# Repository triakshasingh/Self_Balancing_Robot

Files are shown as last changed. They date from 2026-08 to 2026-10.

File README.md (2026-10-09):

# Self-Balancing Robot

A two-wheeled inverted-pendulum robot built around a NodeMCU ESP-32S. The
board carries the MCU, an IMU, a dual H-bridge motor driver and the power rail;
firmware fuses accelerometer and gyroscope readings into a tilt angle and runs a
PID loop that drives the wheels to keep the chassis upright.

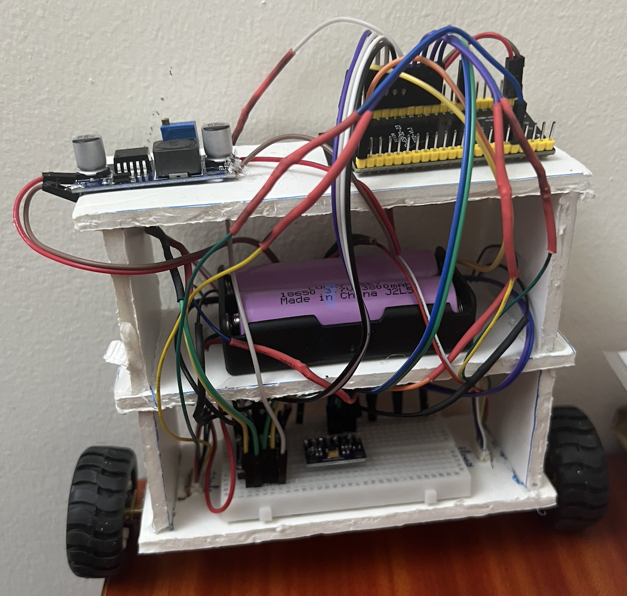
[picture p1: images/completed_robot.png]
Completed robot

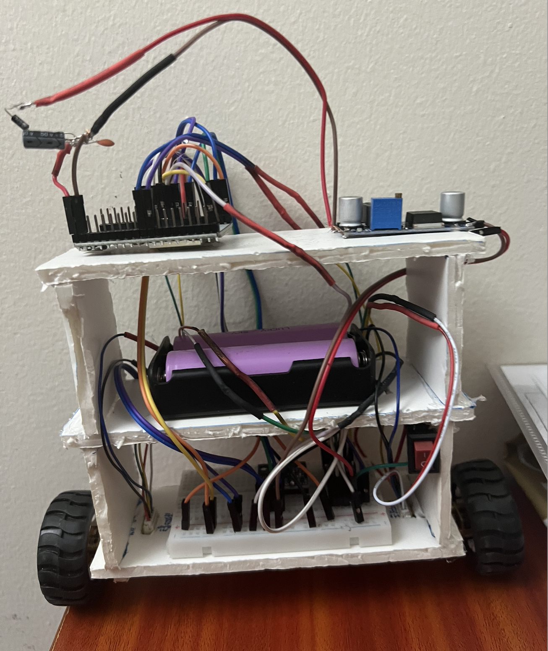
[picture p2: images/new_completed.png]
Rebuilt after board replacement


**During Build**

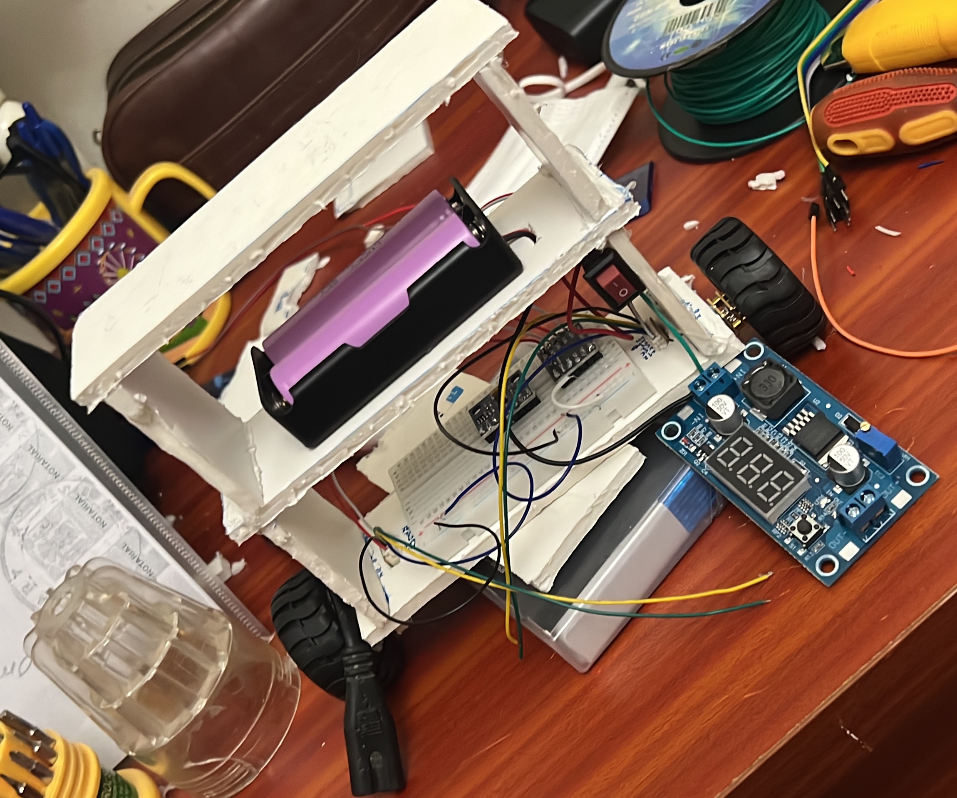
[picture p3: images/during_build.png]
During the build

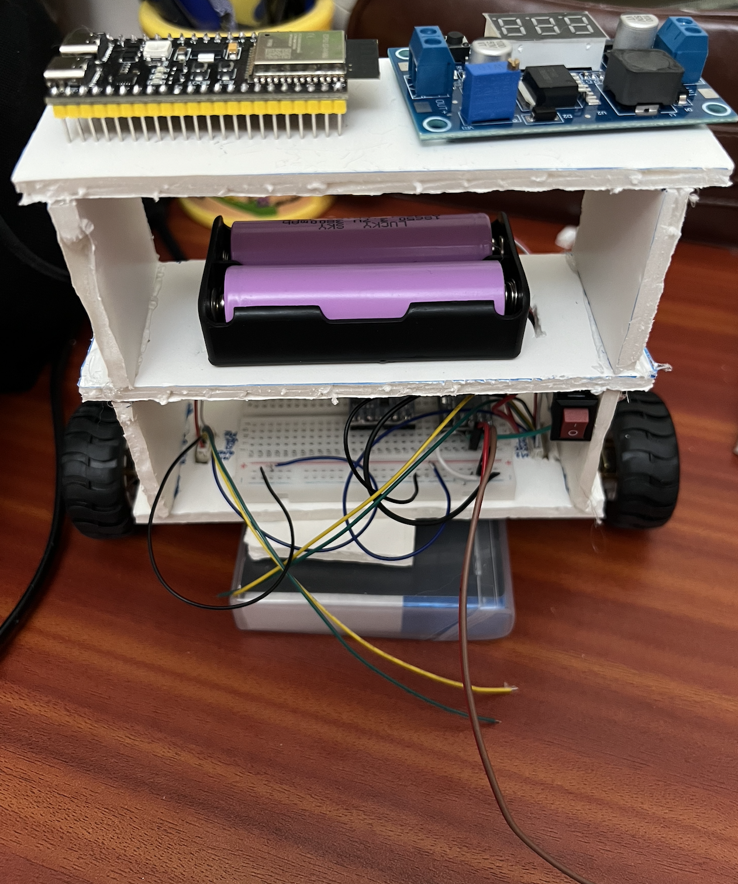
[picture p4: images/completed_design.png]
Design


## Contents

| Path | What's in it |
| --- | --- |
| [PCB/](PCB/) | KiCad 10 project — schematic, board file, project settings |
| [self_balancing_robot_code/self_balancing_robot_code/](self_balancing_robot_code/self_balancing_robot_code/) | Main balancing firmware (Arduino sketch) |
| [self_balancing_robot_code/mpu6050_calibration_only/](self_balancing_robot_code/mpu6050_calibration_only/) | Standalone sketch for finding the upright angle offset |
| [images/](images/) | Build photos and a schematic render |

## Hardware

| Part | Role |
| --- | --- |
| NodeMCU ESP-32S | Main controller, USB programming |
| MPU-6500 (MPU-6050 footprint) | 6-axis IMU over I²C at `0x68` |
| DRV8833PW | Dual H-bridge, drives both gearmotors |
| 2× geared DC motors with quadrature encoders | Drive and wheel odometry |
| Passives | 4.7 kΩ I²C pull-ups, 10 kΩ pull-ups, 0.1 µF / 1 µF / 0.01 µF decoupling |
| Power protection | Backfeed-blocking diode + parallel decoupling capacitors on the 5V rail (added after a brownout incident — see Debugging Notes) |
| 3× push buttons | Boot, reset, user |

The MPU-6500 is pin- and register-compatible with the MPU-6050 footprint used in
the schematic, so the same land pattern works for either part.

### Pin map

GPIO numbers used in the firmware, for the NodeMCU ESP-32S:

| Signal | GPIO |
| --- | --- |
| I²C SDA | 21 |
| I²C SCL | 22 |
| DRV8833 `AIN1` / `AIN2` | 4 / 16 |
| DRV8833 `BIN1` / `BIN2` | 17 / 5 |
| DRV8833 `STBY` | 18 |
| Left encoder `C1` / `C2` | 19 / 23 |
| Right encoder `C1` / `C2` | 25 / 26 |

## PCB

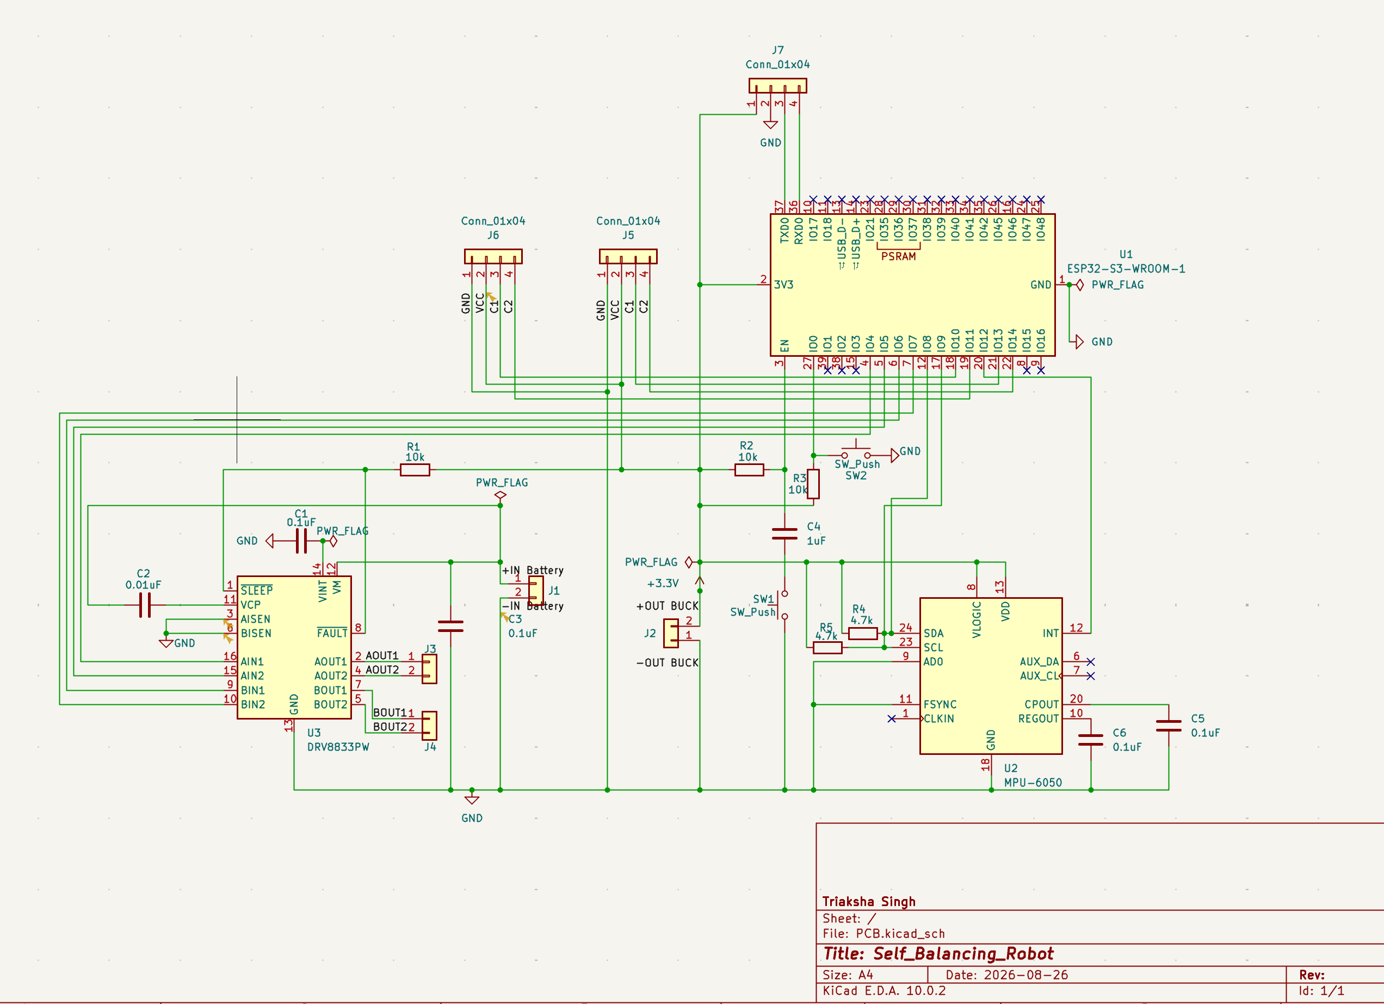
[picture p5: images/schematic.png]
Schematic


## Firmware

Built with the Arduino core for ESP32. Only the bundled `Wire` library is
needed — the IMU is talked to over raw register reads rather than a vendor
driver.

**Arduino IDE setup**

1. Install the ESP32 board package (Boards Manager → *esp32* by Espressif).
2. Select board **NodeMCU-32S**.
3. Set the serial monitor to **115200 baud**.

### How it works

- The IMU is configured for ±4 g and ±500 °/s with the on-chip DLPF enabled.
- `atan2(ax, az)` gives an absolute but noisy tilt angle from the accelerometer;
  the gyro gives a clean but drifting rate.
- A complementary filter blends them at 98 % gyro / 2 % accelerometer each cycle.
- Tilt error feeds a PID controller whose output is written to both motors as a
  signed PWM value.
- If tilt exceeds `FALL_LIMIT` (45°), the motors are cut and the integrator is
  reset so the robot doesn't lurch when picked up.

### Calibration

The robot's "upright" reading is mechanical, not zero, so it has to be measured
once per build.

1. Flash [mpu6050_calibration_only.ino](self_balancing_robot_code/mpu6050_calibration_only/mpu6050_calibration_only.ino),
   hold the robot exactly upright and still, and read the printed `angleOffset`.
   (The main sketch can do the same thing — set `CALIBRATE_ONLY` to `1`.)
2. Put that number into `HARDCODED_OFFSET` in
   [self_balancing_robot_code.ino](self_balancing_robot_code/self_balancing_robot_code/self_balancing_robot_code.ino#L31).
3. Set `CALIBRATE_ONLY` back to `0` and re-flash.

Gyro bias is measured automatically at every boot — leave the robot still for
the couple of seconds after reset while it averages 1000 samples.

### Tuning

Gains live at the top of the main sketch:

```cpp
float Kp = 45;
float Ki = 80;
float Kd = 1.2;
```

Start with `Kp` alone and raise it until the robot oscillates around upright,
then add `Kd` to damp the oscillation, and only then a small `Ki` to remove
steady-state lean. The loop prints tilt, gyro rate, output and both encoder
counts every 100 ms for tuning.

## Results

After PID retuning, the robot balances upright for 30 seconds with 1.7 degrees of steady-state error.

## Debugging Notes

A few real problems came up during this build, kept here because they're more
useful than a clean success story:

- **Arduino IDE partition scheme error** —
  `{build.partitions}.csv: No such file or directory`. Caused by a generic
  "ESP32 Family Device" board selection rather than the specific
  "ESP32S3 Dev Module" — board-specific menus like Partition Scheme don't
  populate until the exact board is selected.
- **Serial Monitor showing nothing, despite working code** — traced through a
  full diagnostic chain (OS-level port detection → Blink-only test →
  Blink+Serial combined test) before finding the actual fault.
- **The real bug: a clone IMU chip.** The MPU6050 breakout actually carries an
  **MPU-6500** — a compatible but distinct sensor that responds on the I²C bus
  (confirmed with a full address scanner) but reports a different `WHO_AM_I`
  value (`0x70` instead of the expected `0x68`). Libraries that strictly check
  this ID (e.g. Adafruit_MPU6050) refuse to initialize on the mismatch even
  though the sensor works fine. Fixed by dropping the library and reading the
  accelerometer/gyro registers directly over raw I²C — the MPU-6500 is
  register-compatible for this purpose.
- **A defective buck converter trimmer pot** — one LM2596 module's adjustment
  range topped out around 7.85 V instead of reaching 5 V, confirmed by feel (a
  mechanical "tick" at the end of its travel) and multimeter cross-checking
  rather than trusting the module's onboard display alone.
- **ESP32-S3 damaged by a brownout loop.** After the board overheated during
  earlier testing, it started rejecting every new firmware upload with
  `Failed to connect to ESP32-S3: No serial data received` — even the manual
  BOOT+RESET bootloader-entry sequence didn't recover it. The board's onboard
  LED was blinking fast and erratically on every power-up, which is the
  classic signature of a **brownout reset loop**: the chip's built-in
  protection resetting it over and over because supply voltage keeps dipping
  below a safe threshold, before it can ever finish booting far enough to
  accept a connection. To confirm whether the instability was coming from the
  board itself or from something in the external wiring, every peripheral
  (IMU, motor driver, encoders) was disconnected and the board powered on
  USB alone — the fast flickering continued completely unchanged, isolating
  the fault to the board itself, most likely a damaged onboard voltage
  regulator no longer able to hold a stable output.

  **Fix:** replaced the board with a NodeMCU ESP-32S, and added protection
  against a repeat — a backfeed-blocking diode in series on the 5V rail (so
  USB power and battery-fed power can never fight each other if both happen
  to be connected at once) plus two decoupling capacitors in parallel (a
  small 0.1 µF ceramic for fast noise, a larger electrolytic as a bulk
  reservoir against slower current dips from the motors). The diode went in
  backwards on the first attempt — reversed, it blocks current entirely
  rather than just dropping voltage, which showed up as 0V instead of the
  expected small drop, and was caught by measuring voltage on both sides of
  it before and after flipping its orientation. The buck converter's output
  was also nudged up slightly afterward, to compensate for the diode's own
  forward voltage drop and keep the ESP32-S3 comfortably within its safe
  input range under load rather than right at the edge of it.

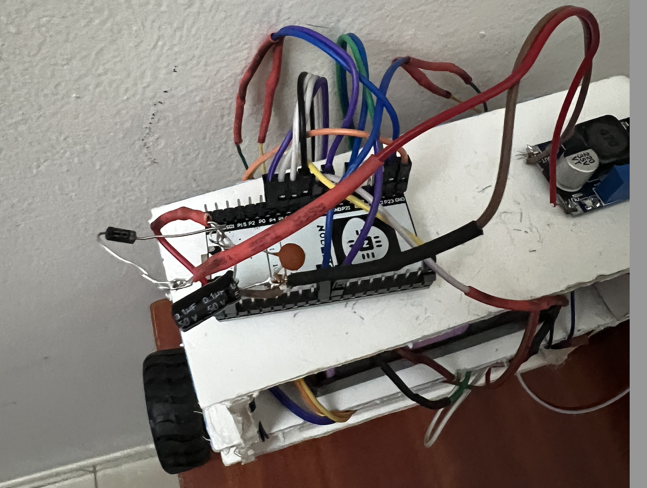
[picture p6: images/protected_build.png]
Diode and capacitor protection circuit
  

## License

[MIT](LICENSE)

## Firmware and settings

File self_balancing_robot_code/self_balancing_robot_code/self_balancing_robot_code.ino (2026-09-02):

#include <Wire.h>

// ============================================================
// PIN MAP
// ============================================================

// MPU-6500 I2C
#define SDA_PIN 21
#define SCL_PIN 22

// DRV8833
#define AIN1 4
#define AIN2 16
#define BIN1 17
#define BIN2 5
#define STBY 18

// Encoders
#define ENC_L_C1 19
#define ENC_L_C2 23
#define ENC_R_C1 25
#define ENC_R_C2 26
// ============================================================
// CALIBRATION SETTINGS
// ============================================================


#define CALIBRATE_ONLY 0

#define HARDCODED_OFFSET 3.9010

// ============================================================
// MPU-6500 REGISTERS
// ============================================================

#define MPU_ADDR 0x68

#define WHO_AM_I     0x75
#define PWR_MGMT_1   0x6B
#define CONFIG        0x1A
#define GYRO_CONFIG   0x1B
#define ACCEL_CONFIG  0x1C
#define ACCEL_XOUT_H  0x3B

const float ACCEL_SCALE = 8192.0;


const float GYRO_SCALE = 65.5;

const float G_TO_MS2 = 9.80665;

// ============================================================
// STATE
// ============================================================

float angle = 0.0;
float angleOffset = 0.0;

float gyroYOffset = 0.0;

unsigned long lastTime = 0;

// ============================================================
// CONTROLLER
// ============================================================


float Kp = 100;
float Ki = 0.0;
float Kd = 0.0;

float setpoint = 0.0;

float integral = 0.0;

const float FALL_LIMIT = 45.0;

// ============================================================
// ENCODERS
// ============================================================

volatile long encLCount = 0;
volatile long encRCount = 0;

void IRAM_ATTR encL_ISR() {
  encLCount += digitalRead(ENC_L_C2) ? 1 : -1;
}

void IRAM_ATTR encR_ISR() {
  encRCount += digitalRead(ENC_R_C2) ? 1 : -1;
}

// ============================================================
// MPU LOW-LEVEL FUNCTIONS
// ============================================================

bool mpuWrite(uint8_t reg, uint8_t value) {

  Wire.beginTransmission(MPU_ADDR);

  Wire.write(reg);
  Wire.write(value);

  return Wire.endTransmission() == 0;
}

bool mpuReadRegister(uint8_t reg, uint8_t &value) {

  Wire.beginTransmission(MPU_ADDR);
  Wire.write(reg);

  if (Wire.endTransmission(false) != 0) {
    return false;
  }

  if (Wire.requestFrom(MPU_ADDR, 1) != 1) {
    return false;
  }

  value = Wire.read();

  return true;
}

// ============================================================
// MPU INITIALIZATION
// ============================================================

bool mpuInit() {

  if (!mpuWrite(PWR_MGMT_1, 0x00)) {
    return false;
  }

  delay(100);

  mpuWrite(CONFIG, 0x04);

  mpuWrite(GYRO_CONFIG, 0x08);

  mpuWrite(ACCEL_CONFIG, 0x08);

  delay(50);

  return true;
}

// ============================================================
// READ MPU DATA
// ============================================================

bool mpuRead(
  float &ax,
  float &ay,
  float &az,
  float &gx,
  float &gy,
  float &gz
) {

  Wire.beginTransmission(MPU_ADDR);

  Wire.write(ACCEL_XOUT_H);

  if (Wire.endTransmission(false) != 0) {
    return false;
  }

  int received = Wire.requestFrom(MPU_ADDR, 14);

  if (received != 14) {
    return false;
  }

  int16_t rawAx =
    ((int16_t)Wire.read() << 8) | Wire.read();

  int16_t rawAy =
    ((int16_t)Wire.read() << 8) | Wire.read();

  int16_t rawAz =
    ((int16_t)Wire.read() << 8) | Wire.read();

  Wire.read();
  Wire.read();

  int16_t rawGx =
    ((int16_t)Wire.read() << 8) | Wire.read();

  int16_t rawGy =
    ((int16_t)Wire.read() << 8) | Wire.read();

  int16_t rawGz =
    ((int16_t)Wire.read() << 8) | Wire.read();

  ax = ((float)rawAx / ACCEL_SCALE) * G_TO_MS2;
  ay = ((float)rawAy / ACCEL_SCALE) * G_TO_MS2;
  az = ((float)rawAz / ACCEL_SCALE) * G_TO_MS2;

  gx = (float)rawGx / GYRO_SCALE;
  gy = (float)rawGy / GYRO_SCALE;
  gz = (float)rawGz / GYRO_SCALE;

  return true;
}

// ============================================================
// ANGLE CALIBRATION
// ============================================================

void calibrateAngle() {

  Serial.println();
  Serial.println("Hold robot PERFECTLY upright and still.");
  Serial.println("Starting angle calibration...");
  delay(2000);

  float sum = 0.0;
  int validSamples = 0;

  float ax, ay, az;
  float gx, gy, gz;

  for (int i = 0; i < 500; i++) {

    if (mpuRead(ax, ay, az, gx, gy, gz)) {

      float accAngle =
        atan2(ax, az) * 180.0 / PI;

      sum += accAngle;

      validSamples++;
    }

    delay(3);
  }

  if (validSamples > 0) {

    angleOffset =
      sum / validSamples;

    angle = angleOffset;

  } else {

    Serial.println("ERROR: no valid MPU samples.");
  }
}

// ============================================================
// GYRO CALIBRATION
// ============================================================

void calibrateGyro() {

  Serial.println();
  Serial.println("Calibrating gyro...");
  Serial.println("DO NOT MOVE THE ROBOT.");

  delay(1000);

  float sumY = 0.0;

  int validSamples = 0;

  float ax, ay, az;
  float gx, gy, gz;

  for (int i = 0; i < 1000; i++) {

    if (mpuRead(ax, ay, az, gx, gy, gz)) {

      sumY += gy;

      validSamples++;
    }

    delay(2);
  }

  if (validSamples > 0) {

    gyroYOffset =
      sumY / validSamples;

    Serial.print("Gyro Y offset = ");
    Serial.println(gyroYOffset, 5);

  } else {

    Serial.println("ERROR: gyro calibration failed.");
  }
}

// ============================================================
// MOTOR CONTROL
// ============================================================

void driveMotors(float speed) {

  bool forward = speed >= 0;

  int pwm =
    constrain((int)fabs(speed), 0, 255);

  // LEFT MOTOR

  analogWrite(
    AIN1,
    forward ? pwm : 0
  );

  analogWrite(
    AIN2,
    forward ? 0 : pwm
  );

  // RIGHT MOTOR

  analogWrite(
    BIN1,
    forward ? pwm : 0
  );

  analogWrite(
    BIN2,
    forward ? 0 : pwm
  );
}

void stopMotors() {

  analogWrite(AIN1, 0);
  analogWrite(AIN2, 0);

  analogWrite(BIN1, 0);
  analogWrite(BIN2, 0);
}

// ============================================================
// SETUP
// ============================================================

void setup() {

  Serial.begin(115200);

  delay(2000);

  Serial.println();
  Serial.println("====================================");
  Serial.println(" SELF BALANCING ROBOT STARTING");
  Serial.println("====================================");

  // ----------------------------------------------------------
  // Motors
  // ----------------------------------------------------------

  pinMode(AIN1, OUTPUT);
  pinMode(AIN2, OUTPUT);

  pinMode(BIN1, OUTPUT);
  pinMode(BIN2, OUTPUT);

  pinMode(STBY, OUTPUT);

  stopMotors();

  digitalWrite(STBY, HIGH);

  // ----------------------------------------------------------
  // Encoders
  // ----------------------------------------------------------

  pinMode(ENC_L_C1, INPUT_PULLUP);
  pinMode(ENC_L_C2, INPUT_PULLUP);

  pinMode(ENC_R_C1, INPUT_PULLUP);
  pinMode(ENC_R_C2, INPUT_PULLUP);

  attachInterrupt(
    digitalPinToInterrupt(ENC_L_C1),
    encL_ISR,
    RISING
  );

  attachInterrupt(
    digitalPinToInterrupt(ENC_R_C1),
    encR_ISR,
    RISING
  );

  // ----------------------------------------------------------
  // I2C
  // ----------------------------------------------------------

  Wire.begin(
    SDA_PIN,
    SCL_PIN
  );

  Wire.setClock(400000);

  Serial.println("I2C started.");

  // ----------------------------------------------------------
  // Find MPU
  // ----------------------------------------------------------

  Wire.beginTransmission(MPU_ADDR);

  if (Wire.endTransmission() != 0) {

    Serial.println();
    Serial.println("ERROR: MPU not found at 0x68.");
    Serial.println("Check SDA, SCL, VCC and GND.");

    stopMotors();

    while (true) {

      Serial.println("MPU NOT FOUND");
      delay(1000);
    }
  }

  Serial.println("MPU detected.");

  // ----------------------------------------------------------
  // Check WHO_AM_I
  // ----------------------------------------------------------

  uint8_t whoAmI = 0;

  if (mpuReadRegister(WHO_AM_I, whoAmI)) {

    Serial.print("WHO_AM_I = 0x");

    if (whoAmI < 0x10) {
      Serial.print("0");
    }

    Serial.println(whoAmI, HEX);

  } else {

    Serial.println("Unable to read WHO_AM_I.");
  }

  // ----------------------------------------------------------
  // Configure MPU
  // ----------------------------------------------------------

  if (!mpuInit()) {

    Serial.println("MPU initialization failed.");

    stopMotors();

    while (true) {
      delay(1000);
    }
  }

  Serial.println("MPU initialized.");

  // ----------------------------------------------------------
  // Calibration
  // ----------------------------------------------------------

#if CALIBRATE_ONLY

  calibrateAngle();

  Serial.println();
  Serial.println("============================");

  Serial.print("angleOffset = ");
  Serial.println(angleOffset, 4);

  Serial.println("============================");

  Serial.println();
  Serial.println("Copy this number into:");
  Serial.println("HARDCODED_OFFSET");

  Serial.println();
  Serial.println("Then set:");
  Serial.println("CALIBRATE_ONLY 0");

  stopMotors();

  while (true) {
    delay(1000);
  }

#else

  angleOffset =
    HARDCODED_OFFSET;

  angle =
    angleOffset;

  Serial.print("Using hardcoded angle offset: ");
  Serial.println(angleOffset, 4);

#endif

  calibrateGyro();

  Serial.println();
  Serial.println("Controller starting.");

  delay(500);

  lastTime = micros();
}

// ============================================================
// LOOP
// ============================================================

void loop() {

  float ax, ay, az;
  float gx, gy, gz;

  // ----------------------------------------------------------
  // Read sensor
  // ----------------------------------------------------------

  if (!mpuRead(
        ax, ay, az,
        gx, gy, gz
      )) {

    stopMotors();

    Serial.println("MPU READ FAILED");

    delay(10);

    return;
  }

  // ----------------------------------------------------------
  // Calculate dt
  // ----------------------------------------------------------

  unsigned long now =
    micros();

  float dt =
    (now - lastTime)
    / 1000000.0;

  lastTime = now;

  if (dt <= 0.0 || dt > 0.05) {

    stopMotors();

    return;
  }

  // ----------------------------------------------------------
  // Accelerometer angle
  // ----------------------------------------------------------

  float accAngle =
    atan2(ax, az)
    * 180.0
    / PI;

  // ----------------------------------------------------------
  // Gyro rate
  // ----------------------------------------------------------

  float gyroRate =
    gy - gyroYOffset;


  // ----------------------------------------------------------
  // Complementary filter
  // ----------------------------------------------------------

  angle =
      0.98
      * (angle + gyroRate * dt)

    + 0.02
      * accAngle;

  float tilt =
    angle - angleOffset;

  // ----------------------------------------------------------
  // Fall safety
  // ----------------------------------------------------------

  if (fabs(tilt) > FALL_LIMIT) {

    stopMotors();

    integral = 0.0;

    return;
  }

  // ----------------------------------------------------------
  // Controller
  // ----------------------------------------------------------

  float error =
    setpoint - tilt;

  integral +=
    error * dt;

  integral =
    constrain(
      integral,
      -50.0,
      50.0
    );


  float output =
      Kp * error
    + Ki * integral
    + Kd * gyroRate;

  output =
    constrain(
      output,
      -255.0,
      255.0
    );

  // ----------------------------------------------------------
  // Motor output
  // ----------------------------------------------------------

  driveMotors(output);

  // ----------------------------------------------------------
  // Optional debug output
  // ----------------------------------------------------------

  static unsigned long lastPrint = 0;

  if (millis() - lastPrint >= 100) {

    lastPrint = millis();

    Serial.print("tilt: ");
    Serial.print(tilt, 2);

    Serial.print("  gyro: ");
    Serial.print(gyroRate, 2);

    Serial.print("  output: ");
    Serial.print(output, 1);

    Serial.print("  encL: ");
    Serial.print(encLCount);

    Serial.print("  encR: ");
    Serial.println(encRCount);
  }
}

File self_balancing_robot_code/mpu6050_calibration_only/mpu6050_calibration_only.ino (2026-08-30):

#include <Wire.h>

#define SDA_PIN 8
#define SCL_PIN 9
#define MPU_ADDR 0x68

#define PWR_MGMT_1   0x6B
#define ACCEL_CONFIG 0x1C
#define GYRO_CONFIG  0x1B
#define ACCEL_XOUT_H 0x3B

const float ACCEL_SCALE = 8192.0;   
const float GYRO_SCALE  = 65.5;     
const float G_TO_MS2    = 9.80665;

void mpuWrite(uint8_t reg, uint8_t val) {
  Wire.beginTransmission(MPU_ADDR);
  Wire.write(reg);
  Wire.write(val);
  Wire.endTransmission();
}

void mpuInit() {
  mpuWrite(PWR_MGMT_1, 0x00);    
  delay(100);
  mpuWrite(ACCEL_CONFIG, 0x08);  
  mpuWrite(GYRO_CONFIG, 0x08);   
}

void mpuRead(float &ax, float &ay, float &az, float &gx, float &gy, float &gz) {
  Wire.beginTransmission(MPU_ADDR);
  Wire.write(ACCEL_XOUT_H);
  Wire.endTransmission(false);
  Wire.requestFrom(MPU_ADDR, 14);

  int16_t rawAx = (Wire.read() << 8) | Wire.read();
  int16_t rawAy = (Wire.read() << 8) | Wire.read();
  int16_t rawAz = (Wire.read() << 8) | Wire.read();
  Wire.read(); 
  Wire.read();   
  int16_t rawGx = (Wire.read() << 8) | Wire.read();
  int16_t rawGy = (Wire.read() << 8) | Wire.read();
  int16_t rawGz = (Wire.read() << 8) | Wire.read();

  ax = (rawAx / ACCEL_SCALE) * G_TO_MS2;
  ay = (rawAy / ACCEL_SCALE) * G_TO_MS2;
  az = (rawAz / ACCEL_SCALE) * G_TO_MS2;
  gx = rawGx / GYRO_SCALE;
  gy = rawGy / GYRO_SCALE;
  gz = rawGz / GYRO_SCALE;
}

void setup() {
  Serial.begin(115200);
  delay(1000);
  Serial.println("=== MPU-6500 calibration-only sketch starting ===");

  Wire.begin(SDA_PIN, SCL_PIN);

  Wire.beginTransmission(MPU_ADDR);
  if (Wire.endTransmission() != 0) {
    Serial.println("FAILED — nothing responded at 0x68. Check wiring/power.");
    while (1) delay(1000);
  }

  mpuInit();
  Serial.println("SUCCESS — sensor initialized.");

  Serial.println();
  Serial.println("Hold the robot exactly upright and still now.");
  Serial.println("Calibration starts in 3 seconds...");
  delay(3000);

  float sum = 0;
  float ax, ay, az, gx, gy, gz;
  for (int i = 0; i < 200; i++) {
    mpuRead(ax, ay, az, gx, gy, gz);
    sum += atan2(ax, az) * 180.0 / PI;
    delay(3);
  }
  float angleOffset = sum / 200.0;

  Serial.println();
  Serial.print("DONE. angleOffset = ");
  Serial.println(angleOffset, 4);
  Serial.println("Copy this number down for use in the main sketch.");
}

void loop() {
  float ax, ay, az, gx, gy, gz;
  mpuRead(ax, ay, az, gx, gy, gz);
  float angle = atan2(ax, az) * 180.0 / PI;

  Serial.print("Live accelerometer angle: ");
  Serial.println(angle, 2);
  delay(200);
}

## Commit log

2026-08-30 adding self_balancing files and docs
    [PCB.kicad_pcb, PCB.kicad_sch]
2026-09-02 Change ESP32-S3 references to NodeMCU ESP-32S
    Updated references from ESP32-S3 to NodeMCU ESP-32S in the README.
2026-09-02 Update README with ESP32-S3 damage details
    Expanded explanation of ESP32-S3 damage and repair process, detailing symptoms, diagnosis, and fixes implemented to prevent future issues.
2026-10-09 Add results section to README
    Added results section to document PID retuning outcomes.
